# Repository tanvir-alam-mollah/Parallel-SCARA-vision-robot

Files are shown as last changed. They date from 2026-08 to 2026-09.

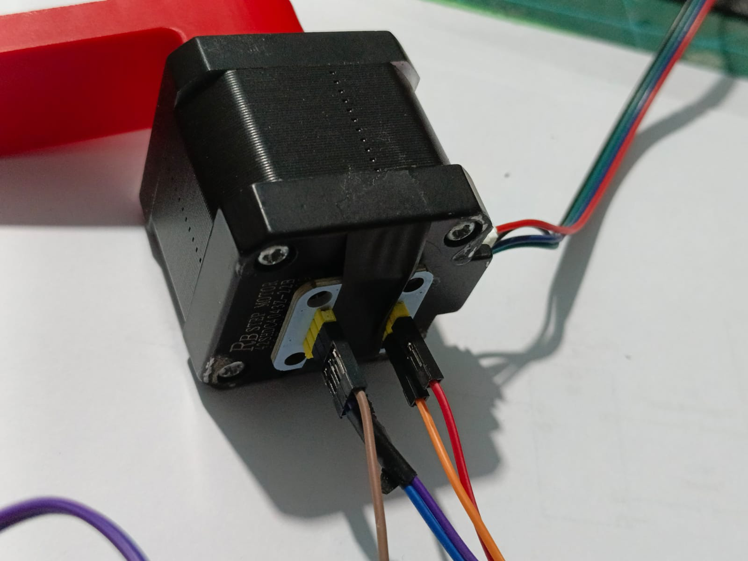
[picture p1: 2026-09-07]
image and videos/encoder Mounting2.jpeg

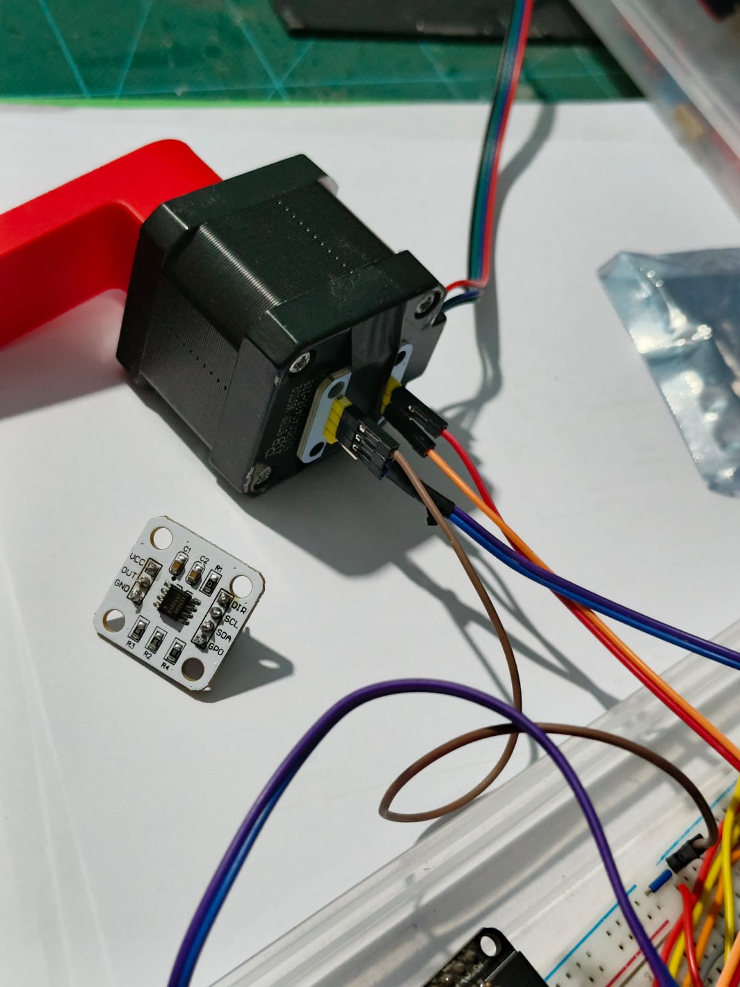
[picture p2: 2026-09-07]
image and videos/encoder Mounting.jpeg

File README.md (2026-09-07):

# Autonomous 5-Bar Parallel SCARA Manipulator
**Developer:** Md Tanvir Alam Mollah, Mechatronics Engineering, KUET  
**Domain:** Autonomous Systems Integration & Closed-Loop Robotics  





## 📌 Project Overview
A direct-drive, 2-DOF parallel robotic manipulator designed for fully autonomous pick-and-place operations. This project bridges advanced mechanical kinematics with real-time computer vision, allowing the system to identify targets within a calibrated workspace, compute real-world cartesian coordinates, and execute precision sorting using a custom electromagnet end-effector. 

To guarantee absolute physical precision, the system incorporates a closed-loop feedback architecture. By utilizing AS5600 magnetic encoders to count the physical steps of the stepper motors, the microcontroller continuously verifies the true position of the end-effector against the calculated kinematic targets.

## ✨ Key Features
*   **Dynamic Inverse Kinematics (IK):** Mathematical IK natively derived and executed on the ESP32 to calculate complex joint angles in real time.
*   **Closed-Loop Position Feedback:** Dual AS5600 magnetic encoders count the physical steps executed by the NEMA 17 motors, verifying the exact position of the end-effector and forming a precise error-correction feedback loop.
*   **Computer Vision Pipeline:** OpenCV-based object detection over an IP camera stream, transforming pixel data into real-world cartesian coordinates (0.875 mm/px scale).
*   **Visual Auto-Homing (`VHOME`):** The system dynamically calibrates its starting coordinate by visually locating a fiducial marker on the end-effector at startup, eliminating the need for hardcoded home steps.
*   **Handshake Protocol Automation:** A robust serial communication architecture between Python and the ESP32 that orchestrates the full autonomous task loop (Identify $\rightarrow$ Grasp $\rightarrow$ Transport $\rightarrow$ Release $\rightarrow$ Reset).
*   **Live UI/UX Overlay:** Projects a persistent 100mm physical coordinate grid directly onto the video feed to monitor the manipulator's reach and spatial accuracy continuously.

## 🛠️ Hardware Architecture
*   **Microcontroller:** ESP32 DevKit V1
*   **Actuators:** 2x NEMA 17 Stepper Motors (Direct Drive) driven by DRV8825 modules (1/32 Microstepping).
*   **Position Feedback:** 2x AS5600 High-Resolution Magnetic Encoders operating on independent hardware I2C buses.
*   **End-Effector:** 5V DC Electromagnet (P25/20, 5kg holding capacity, 0.6A draw) controlled via a 1-Channel 5V Relay.
*   **Logic Level Management:** 3.3V to 5V relay mismatch resolved via software-defined High-Impedance switching (`pinMode` toggling).

## 📐 Mechanical Workspace & Kinematics
*   **Base Origins:** Left Motor (X: -40.0, Y: 0.0) | Right Motor (X: 40.0, Y: 0.0)
*   **Linkages:** Base Links (110.0 mm) | End Links (160.0 mm)
*   **Trajectory:** Uses `FastAccelStepper` for interrupt-driven trapezoidal motion profiling (Acceleration: 2000 steps/s²).

## 🚀 Current Status & Next Steps
The manipulator's kinematics, vision pipeline, and open-loop control are fully operational.

**Active Development:** Implementing the closed-loop feedback system. Dual AS5600 magnetic encoders are being mapped via independent hardware I2C buses to count the exact physical steps of the NEMA 17 motors. This feedback loop will continuously verify the mechanical execution of the Inverse Kinematics, ensuring the end-effector has successfully reached the assigned coordinates and compensating for any missed stepper motor steps.

---

### 📂 Repository Structure
*   `/firmware` - ESP32 C++ source code, kinematics math, and stepper control logic.
*   `/vision` - Python scripts for OpenCV target tracking, auto-homing, and serial communication.
*   `/docs` - Wiring diagrams, mechanical parameters, and system architecture notes.
*   `/cad` - 3D models and assembly files for the 5-bar linkage system.



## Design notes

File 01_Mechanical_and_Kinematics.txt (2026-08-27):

PROJECT: 5-Bar Parallel SCARA Manipulator
=========================================
DESCRIPTION: 
A direct-drive 2-DOF parallel robotic manipulator designed for automated pick-and-place operations. The system uses a computer vision pipeline to dynamically calculate inverse kinematics and physically sort objects using an electromagnet end-effector.

MECHANICAL PARAMETERS:
- Actuators: 2x NEMA 17 Stepper Motors (Direct Drive)
- End-Effector: 5V DC Electromagnet (Model: P25/20, 5kg holding force, 0.6A current draw)
- Workspace Base Origins: 
  - Left Motor (Base 1): X = -40.0 mm, Y = 0.0 mm
  - Right Motor (Base 2): X = 40.0 mm, Y = 0.0 mm
- Linkage Dimensions:
  - Base Links (Link 1 & Link 2): 110.0 mm
  - End Links (Link 3 & Link 4): 160.0 mm

KINEMATICS:
The system uses mathematical Inverse Kinematics (IK) to convert cartesian target coordinates (X, Y) into radian joint angles for the stepper motors. The formula utilizes the law of cosines and trigonometric mapping (atan2, hypot) to constantly ensure targets fall within the physical envelope of the mechanical linkages.

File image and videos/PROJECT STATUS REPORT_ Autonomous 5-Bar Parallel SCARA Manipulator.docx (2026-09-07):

# PROJECT STATUS REPORT: Autonomous 5-Bar Parallel SCARA Manipulator

Date: September 7, 2026

## 1. Ultimate Project Objective

The overarching objective of this project is to engineer, program, and validate a fully autonomous, closed-loop 5-bar parallel SCARA robotic manipulator capable of visual targeting and physical object sorting.

The system bridges advanced mechanical kinematics with real-time computer vision to identify targets within a physical workspace, compute precise real-world cartesian coordinates, and execute pick-and-place operations using a specialized electromagnet end-effector.

To ensure research-grade physical precision, the ultimate iteration of this system integrates a strict closed-loop feedback architecture. By mapping dual AS5600 magnetic encoders to the stepper motor shafts, the microcontroller will continuously verify the mechanical execution of the Inverse Kinematics (IK), establishing a real-time error-correction loop that guarantees absolute end-effector positional accuracy.

## 2. Progress Update: Completed Milestones

The project has successfully transitioned through the foundational mechanical, electrical, and software phases. The system is currently fully operational in an open-loop state.

Previously:

1. Kinematics & Motion Control (Firmware):
  a. Successfully derived and embedded mathematical Inverse Kinematics natively onto the ESP32 to calculate complex joint angles in real time.
  b. Configured NEMA 17 stepper motors with DRV8825 drivers, utilizing the FastAccelStepper library for high-speed, interrupt-driven trapezoidal motion profiling.
2. Electrical & End-Effector Integration:
  a. Successfully integrated a 5V DC Electromagnet (P25/20) with a ~5kg holding capacity.
  b. Resolved a critical 3.3V-to-5V hardware logic-level mismatch on the control relay by implementing software-defined High-Impedance state switching (pinMode toggling).
  c. Stabilized the magnetic coil with a dedicated 2A external power supply, optimizing magnetic flux dwell times for reliable payload securing.

Last 2 weeks:

3. Computer Vision Pipeline (Software):
  a. Deployed an OpenCV-based tracking pipeline over an IP Web camera stream, accurately transforming detected pixel data (u,v) into real-world cartesian coordinates (x,y).
  b. Calibrated to a 0.875 mm/px scale.
4. Full-Cycle Autonomy:
  a. Established a robust serial "Handshake Protocol" between Python and the ESP32.
  b. Implemented a visual auto-homing sequence (VHOME) that dynamically calibrates the manipulator's starting coordinates by visually locating a green fiducial marker on the end-effector.
  c. Automated the comprehensive task loop (VPICK): Target identification, precision grasping, transport to a designated drop zone (X: 150, Y: 0), payload release, and safe retreat (X: 0, Y: 150).

UPLOAD THE VIDEO!!

## 3. Ongoing Tasks: The Closed-Loop Integration Roadmap

While the open-loop system functions smoothly, the manipulator currently relies blindly on the stepper motors executing their commanded step counts. The final phase of the project is entirely focused on hardware feedback and error correction.

### Immediate Objectives (Hardware & Wiring)

- Dual I2C Bus Configuration: Wire the two AS5600 magnetic encoders to the ESP32. Because the AS5600 has a hardcoded I2C address (0x36), the sensors will be wired to the ESP32's two independent hardware I2C buses (Bus 0: GPIO 25/27, Bus 1: GPIO 32/33) to prevent signal clashing without requiring a multiplexer.
- Baseline Sensor Validation: Write and execute standalone diagnostic firmware to ensure both encoders smoothly output 12-bit raw angle data (0–4095) across a full 360-degree rotation of the NEMA 17 shafts.

### Secondary Objectives (Software & Algorithms)

- Resolution Mapping: Develop the mathematical conversion matrix to bridge the gap between the NEMA 17's microstepping resolution (6,400 steps per revolution at 1/32 mode) and the AS5600's fixed magnetic tick resolution (4,096 ticks per revolution).
- Closed-Loop Feedback Implementation:
  - Modify the main execution loop to read the starting AS5600 angles prior to movement.
  - Command the physical step sequence derived from the IK calculations.
  - Read the post-movement AS5600 angles, convert the raw data into degrees, and compare it against the IK target angles.
  - Calculate the discrepancy (error margin) and command corrective micro-steps if the end-effector falls short of the target coordinate.

### Remaining Tasks:

1. 3d print the workspace setup and fully mount the system
2. Calibration
3. System Benchmarking: Run extensive pick-and-place cycles under varying speeds and payloads to document the correction latency and overall positional accuracy of the closed-loop system.
4. Documentation: Finalize code commenting, GitHub repository archiving, and compile the final thesis/project report.

Git repo:

https://github.com/tanvir-alam-mollah/Parallel-SCARA-vision-robot.git

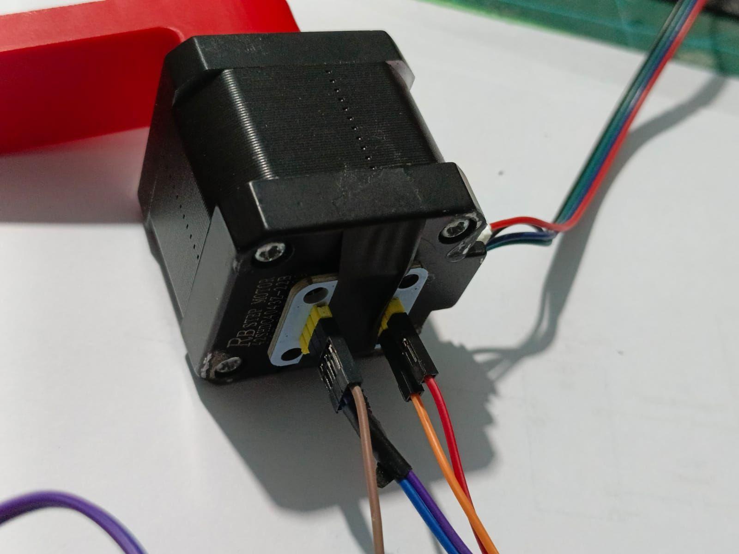
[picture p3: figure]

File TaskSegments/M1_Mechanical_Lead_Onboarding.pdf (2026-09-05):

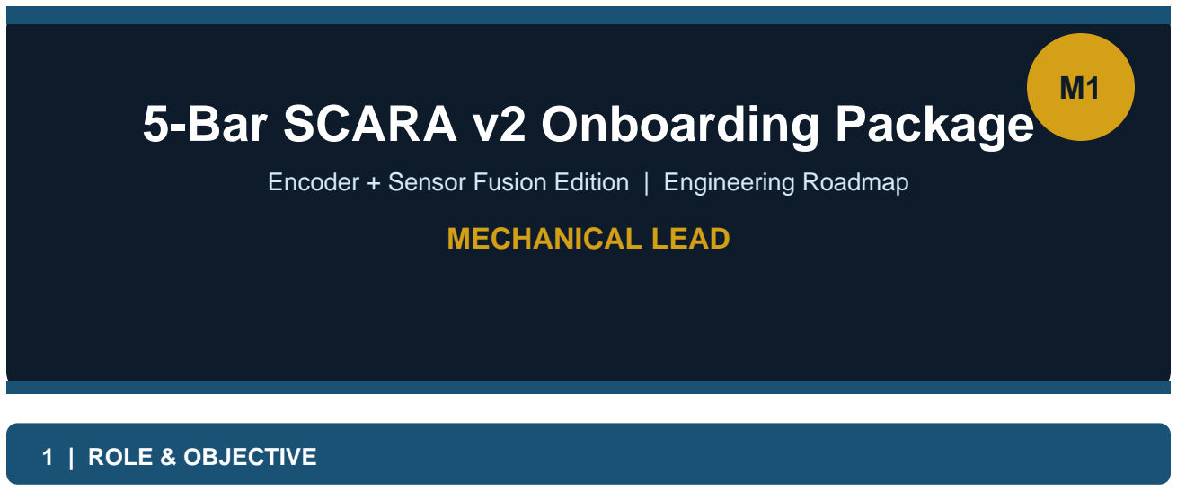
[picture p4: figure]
5-Bar SCARA v2 Onboarding Package; MECHANICAL LEAD; 1 | ROLE & OBJECTIVE

### Encoder + Sensor Fusion Edition | Engineering Roadmap

As Mechanical Lead (M1), you are the geometric and physical foundation of the entire project. Your mission is two-fold: extract precise kinematic parameters (L1–L4, d) to ±0.1 mm, and physically mount and validate the rotary encoders on both NEMA 17 motor shafts. Every downstream firmware component — IK solver, closed-loop correction, collision detection — depends on the accuracy of your measurements. You own Phase 1 outright and provide hardware support for Phase 2B.
Primary Mission: Deliver a fully-populated config.h with all geometric and encoder constants, verified by oscilloscope, and committed to Git before M2 can begin Phase 2B.

### 2 | HARDWARE & COMPONENTS REQUIRED

Component | Specification / Notes | Quantity
NEMA 17 Stepper Motors | Already installed on SCARA frame | 2
Rotary Encoder (Magnetic) | AS5600 I2C OR LPD3806-600BM-G5-24C quadrature, 600 PPR | 2
Encoder Mounting Brackets | Custom-printed or machined; must be rigid (zero flex) | 2
Digital Calipers | Resolution ±0.01 mm; calibrated | 1
Dial Indicator + Magnetic Stand | For runout check — must verify < 0.1 mm eccentricity | 1
Oscilloscope / Logic Analyzer | To verify clean A/B quadrature square waves at full speed | 1
Decoupling Capacitors | 100 nF ceramic; 1 per encoder signal line (4 total) | 4+
Shielded Signal Cable | For A/B encoder channels; route away from motor power leads | As needed
Alignment Tape / Marker | Physical home-position marking on workspace | 1
Screws, Standoffs, Epoxy | For rigid bracket + motor housing attachment | Assorted

### 3 | SOFTWARE & PLATFORMS REQUIRED

5-Bar SCARA v2 | M1 — Mechanical Lead | CONFIDENTIAL — Internal Use Only
Page 2 | 5-Bar Parallel SCARA — Onboarding Document | M1
Tool / Library | Purpose | Installation
Arduino IDE 2.x or PlatformIO | Edit and verify config.h constants | arduino.cc / platformio.org
ESP32 Board Package (Espressif) | For ESP32 pin definitions referenced in
config.h | Board Manager URL
Git (CLI or GitHub Desktop) | Version control — commit v0.0-baseline
and config.h | git-scm.com
VSCode + C/C++ Extension | Syntax highlighting for config.h editing | code.visualstudio.com
Logic Analyzer Software | Pulseview (open source) to decode
quadrature signals | sigrok.org
Spreadsheet (Excel / Sheets) | Record 5x measurement sets and
compute means | Office / Google

### 4 | AI INTEGRATION STRATEGY

Use AI to validate your measurements, automate config.h generation, and troubleshoot encoder wiring. Below are specific, copy-paste-ready prompt strategies:

### Prompt 1 — Generate config.h from your measurements:

"I measured the 5-bar SCARA linkage parameters: L1=118.4mm, L2=120.1mm, L3=117.9mm, L4=119.6mm, d=95.0mm. The encoder is LPD3806 with 600 PPR using quadrature x4 decoding. Generate a complete config.h with all constexpr values, GPIO pin assignments for ESP32 interrupt-capable pins, and inline comments explaining each constant. Format it as Arduino C++."

### Prompt 2 — Diagnose encoder signal quality:

"I see my quadrature encoder A/B signals on oscilloscope. The A channel has clean edges but B channel has a 50ns ringing glitch after each edge. My wiring runs parallel to the stepper motor coil wires for ~15cm. What are the likely causes and fixes? Explain EMI coupling and decoupling capacitor placement."

### Prompt 3 — Validate bracket design:

"I need to mount a rotary encoder to a NEMA 17 motor shaft. The encoder body must not flex. List the mechanical design requirements for the bracket, runout constraints, and how to verify concentricity with a dial indicator. Provide a step-by-step procedure."

### 5 | BASIC ARCHITECTURE & CONNECTIONS

Your Deliverable | Connects To | Why It Matters
config.h (L1–L4, d) | M2 — IK Solver (Phase 2) | IK math uses these exact values; 1mm error
= positioning fault
Encoder PPR, GPIO pins | M2 — Encoder ISR (Phase 2B) | ISR must know which GPIO and CPR to
decode counts correctly
Physical home marker | M6 — Baseline Audit
(Pre-Phase)

M6 needs reference position before Git commit

Encoder wire routing | M5 — Reviewer (Phase 2B) | M5 checks EMI isolation and signal integrity
Oscilloscope verification | M5 — TEST 1-D sign-off | Gate requirement; no clean signal = Phase 1
blocked

Page 3 | 5-Bar Parallel SCARA — Onboarding Document | M1
Your Deliverable | Connects To | Why It Matters

Rigid bracket + runout <

0.1mm | M2 — Closed-loop accuracy | Mechanical slop propagates into position
error directly

Data Flow: M6 baseline commit → M1 physical measurements + encoder mount → M2 IK firmware → M2 encoder ISR → M4 integration → M5/M6 validation

### 6 | TIMELINE & MILESTONES

[ DAY 1 ]
- Attend kickoff with M6 — confirm Git repo access and review v0.0-baseline tag
- Gather all measurement tools (calipers, dial indicator, oscilloscope)
- Print or acquire encoder mounting brackets; order encoders if not in stock
- Review config.h skeleton from M6's Pre-Phase deliverable

[ DAYS 2–3 (Phase 1 Core) ]
- Measure L1, L2, L3, L4 five times each — record in spreadsheet, compute means
- Measure d (motor pivot separation) five times — record mean
- Measure joint backlash in ±X and ±Y with dial indicator
- Mark and photograph world frame origin on workspace surface

[ DAYS 3–4 (Encoder Mounting — NEW v2) ]
- Mount encoder body to motor housing using rigid bracket (zero flex)
- Attach encoder disk to motor shaft — verify concentricity with dial indicator (runout < 0.1mm)
- Route A/B cables AWAY from motor power wires; add 100nF decoupling caps at ESP32 pins
- Connect encoder to ESP32 on interrupt-capable pins (ENC1_A=34, ENC1_B=35, ENC2_A=36, ENC2_B=39)

[ DAY 5 (Verification Gate) ]
- Oscilloscope check: clean square waves on A and B at full motor speed — no glitches
- Populate config.h: L1–L4, d, ENCODER_PPR=600, ENC_CPR=2400, GPIO pin assignments
- Commit config.h to Git — coordinate with M6 for tag/branch naming
- M5 reviews: TEST 1-A through 1-E — obtain sign-off

[ PHASE 2B HW SUPPORT ]
- Support M2 during encoder homing: zero both encoder counts at physical home position
- Verify 3 known angles physically — confirm encoder within ±2 counts of expected
- If stall detection triggers incorrectly: check for mechanical binding, tighten bracket
- Sign off on Phase 2B HW portion with M5 and M2

### 7 | ESCALATION MATRIX

Issue / Blocker | First Contact | Second Contact | Notes

Measurement ambiguity /

linkage geometry unclear | M6 (Systems Lead) | M2 (uses values in IK) | Remeasure and document
| | disagreement
| | lines
Self-resolve: redesign bracket | M6 for fabrication resources | Do NOT proceed to firmware until resolved

Encoder signal glitches persist

after decoupling caps | M2 (Firmware) | M5 (Test Lead) | Try ferrite bead on signal

Encoder bracket flexes —
runout > 0.1mm

Page 4 | 5-Bar Parallel SCARA — Onboarding Document | M1
Issue / Blocker | First Contact | Second Contact | Notes
GPIO pin conflict with M2's firmware | M2 (pin ownership) | M6 (config arbitration) | Update config.h together
Git merge conflict on config.h | M6 (Git custodian) | M4 (Integration) | M6 resolves baseline conflicts
Phase gate blocked — M5 not available for review | M5 directly | M6 for escalation | Gate CANNOT be bypassed

You are the physical foundation of this system. Every millimeter of precision you deliver multiplies through the entire kinematic chain. Measure twice, commit once. You've got this. ■

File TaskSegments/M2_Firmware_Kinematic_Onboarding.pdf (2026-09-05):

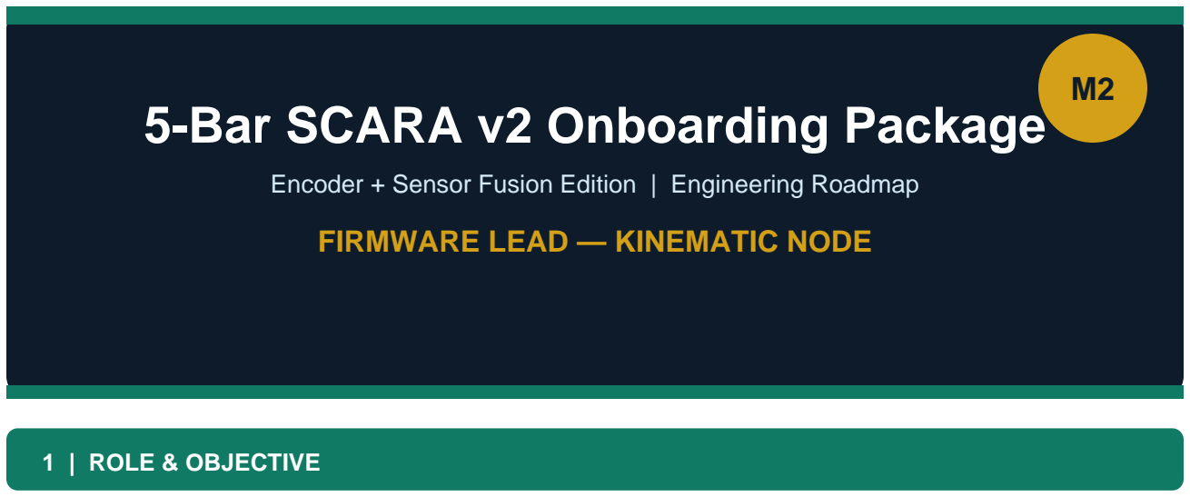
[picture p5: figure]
5-Bar SCARA v2 Onboarding Package; FIRMWARE LEAD — KINEMATIC NODE; 1 | ROLE & OBJECTIVE

### Encoder + Sensor Fusion Edition | Engineering Roadmap

As Firmware Lead — Kinematic Node (M2), you are the computational brain of the robot arm. Your mission spans two critical phases: Phase 2 — build the closed-form IK solver, 2D collision monitor, and interrupt-driven state machine (open-loop baseline); and Phase 2B — layer quadrature encoder decoding, a closed-loop position correction engine, and stall detection onto that foundation. You also serve as reviewer for M1's mechanical output.
Primary Mission: Deliver firmware on the ESP32 (dual-core) that reliably accepts FusionPackets from M4, resolves inverse kinematics, drives AccelStepper motors, and uses encoder feedback to verify and correct each commanded position — all in real time without blocking the main loop.

### 2 | HARDWARE & COMPONENTS REQUIRED

Component | Specification / Notes | Qty
ESP32 Dev Board (dual-core) | Main kinematic processing node; must have 4
interrupt-capable GPIO free | 1
DRV8825 Stepper Drivers | One per motor; set microstepping to 1/16 or 1/32 | 2
NEMA 17 Stepper Motors | As mounted by M1 on SCARA frame | 2
Rotary Encoders (mounted by M1) | LPD3806 600PPR or AS5600; A/B signals on GPIO
34,35,36,39 | 2
Power Supply (12V, >3A) | For DRV8825 VMot; separate from ESP32 3.3V rail | 1
Logic Level Converter | If encoder signals are 5V — convert to 3.3V for ESP32 | As
needed
Oscilloscope / Serial Monitor | Verify ISR counts, step pulses, correction loop
behavior | 1
USB-to-Serial Adapter | For flashing and Serial monitor on ESP32 | 1

### 3 | SOFTWARE & PLATFORMS REQUIRED

Tool / Library | Purpose | Source
Arduino IDE 2.x or PlatformIO | Primary firmware development
environment | arduino.cc / platformio.org

5-Bar SCARA v2 | M2 — Firmware Lead (Kinematic) | CONFIDENTIAL — Internal Use Only
Page 2 | 5-Bar Parallel SCARA — Onboarding Document | M2
Tool / Library | Purpose | Source
Espressif ESP32 Board Package | FreeRTOS, IRAM_ATTR, hardware timers, noInterrupts() | Board Manager
AccelStepper Library | Non-blocking stepper motor control (.run() in main loop) | Library Manager
ESP-NOW (built-in) | Receive FusionPacket from M4's vision bridge | Included in ESP32 core
FreeRTOS (built-in) | Run stall detection check_stall() as a timed task | Included in ESP32 core
Git | Version control; review M1's config.h before Phase 2 | git-scm.com
Python + matplotlib (optional) | Plot encoder count vs. step count during calibration | pip install matplotlib

### 4 | AI INTEGRATION STRATEGY

Your work is mathematically dense (IK geometry, ISR timing, FreeRTOS task scheduling). Use AI as a pair-programmer for derivation verification, ISR debugging, and test generation:

### Prompt 1 — Verify your IK math (law of cosines):

"I have a 5-bar parallel SCARA with Motor 1 at P1=(-d/2, 0) and Motor 2 at P2=(+d/2, 0). Link lengths are L1=118.4, L2=120.1, L3=117.9, L4=119.6, d=95.0 (all mm). Derive the closed-form elbow-out IK solution for both chains using law of cosines. Show the atan2+alpha formulation for theta1 and theta2. Clamp cos values to [-1,1]. Return as Arduino C++ function IKResult solve_ik(float x, float y)."

### Prompt 2 — Debug quadrature ISR jitter:

"My ESP32 quadrature decoder ISR uses the QEM[16] lookup table. At high motor speeds I see occasional count errors of +2 or -2 per revolution. The encoder is 600PPR. Diagnose possible causes: bounce, cache miss latency, simultaneous A+B edge timing. How does IRAM_ATTR help? What is the maximum safe RPM before ISR misses edges?"

### Prompt 3 — Generate TEST 2-A validation code:

"Generate an Arduino test sketch that validates my IK solver with 20 random (x,y) workspace points. For each point: call solve_ik(), then forward-kinematics to recover (x,y), then compute Euclidean error. Print PASS if all errors < 0.5mm, FAIL otherwise. Include the forward kinematics for a 5-bar parallel robot given theta1, theta2, L1-L4, d."

### Prompt 4 — State machine review:

"Review this RobotState enum and main loop pattern for a pick-and-place robot: [paste your state machine code]. Identify any blocking call that would starve AccelStepper.run(), any state transition that could skip a state under fast packet arrival, and any missing FAULT recovery path."

### 5 | BASIC ARCHITECTURE & CONNECTIONS

Input From | Your Processing | Output To

M1: config.h (L1–L4, d, GPIO,
PPR)
| IK solver reads all geometric constants at
compile time
| | M4: acknowledgment + motor
state

Page 3 | 5-Bar Parallel SCARA — Onboarding Document | M2
Input From | Your Processing | Output To
M4: FusionPacket (X,Y,Vx,Vy,confidence) | Parse packet → IK → collision check → moveTo() | DRV8825 → NEMA 17 motors
Encoders (A/B pulses via ISR) | Quadrature decode → angle comparison → correction move | M5: stall alerts via Serial
M1: home position marker | Zero encoder counts at startup homing routine | M5 reviewer: Phase 2B gate
M3: velocity hints (Vx,Vy) | Pre-position if confidence > 180 threshold | Reduced pick latency

Core Loop: ESP-NOW ISR (IRAM_ATTR) receives FusionPacket → main loop reads g_target → solve_ik() → check_collision() → moveTo() → motor1.run()/motor2.run() → apply_correction() → check_stall() [50ms hardware timer]

### 6 | TIMELINE & MILESTONES

[ DAY 1 ]
- Pull config.h from M1 (or Git baseline) — read all geometric constants
- Set up PlatformIO project with ESP32 target and AccelStepper dependency
- Stub out IKResult struct and solve_ik() function signature
- Coordinate with M4 on FusionPacket struct definition (v2 version)

[ DAYS 2–5 (Phase 2 — IK Solver & State Machine) ]
- Implement IK solver: law of cosines, atan2 + alpha, elbow-out branch for both chains
- Implement 2D collision monitor using cross-product segment intersection
- Build state machine: IDLE → HOMING → MOVING_TO_PICK → PICKING → MOVING_TO_DROP → DROPPING → FAULT
- TEST 2-A: IK round-trip error < ±0.5mm on 20 random workspace points
- TEST 2-B: Collision detector 100% accuracy on 20 known test cases
- TEST 2-C: State machine driven by Serial mock packets — full IDLE→PICK→DROP→IDLE cycle
- TEST 2-D: Out-of-workspace target silently rejected
- M1 reviews Phase 2 — obtain sign-off

[ DAYS 6–8 (Phase 2B — Encoder Closed-Loop) ]
- Implement isr_enc1() and isr_enc2() with IRAM_ATTR and QEM[16] lookup table
- Implement attach_encoders() with CHANGE interrupts on all 4 encoder pins
- Thread-safe get_enc1_angle_deg() and get_enc2_angle_deg() with noInterrupts()
- Implement apply_correction(): proportional correction loop, max 3 attempts
- Implement check_stall(): 50ms FreeRTOS timer, STALL_COUNT_THRESHOLD=20 counts
- TEST 2B-A: Encoder direction — +90° command → count = +ENC_CPR/4
- TEST 2B-B: Correction triggered when linkage manually held
- TEST 2B-C: FAULT triggered within 700ms of shaft block
- TEST 2B-D: 10 pick positions, encoder error < ±1.5 deg each
- TEST 2B-E: Zero drift in 30 seconds idle
- M5 reviews Phase 2B — obtain sign-off

### 7 | ESCALATION MATRIX

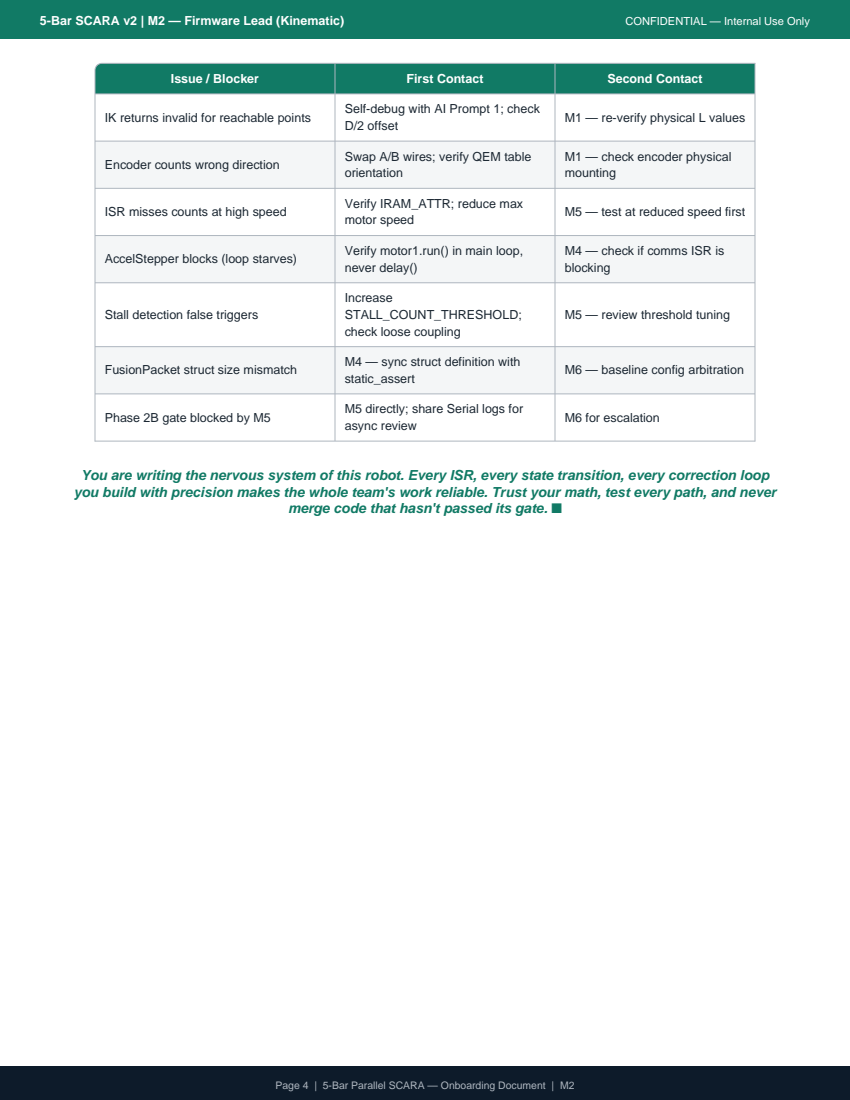
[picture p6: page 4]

Issue / Blocker | First Contact | Second Contact

IK returns invalid for reachable points | Self-debug with AI Prompt 1; check D/2 offset | M1 — re-verify physical L values

Encoder counts wrong direction | Swap A/B wires; verify QEM table orientation | M1 — check encoder physical mounting

ISR misses counts at high speed | Verify IRAM_ATTR; reduce max motor speed | M5 — test at reduced speed first

AccelStepper blocks (loop starves) | Verify motor1.run() in main loop, never delay() | M4 — check if comms ISR is blocking

Stall detection false triggers | Increase STALL_COUNT_THRESHOLD; check loose coupling | M5 — review threshold tuning

FusionPacket struct size mismatch | M4 — sync struct definition with static_assert | M6 — baseline config arbitration

Phase 2B gate blocked by M5 | M5 directly; share Serial logs for async review | M6 for escalation

You are writing the nervous system of this robot. Every ISR, every state transition, every correction loop
you build with precision makes the whole team's work reliable. Trust your math, test every path, and never

merge code that hasn't passed its gate. ■

Page 4 | 5-Bar Parallel SCARA — Onboarding Document | M2

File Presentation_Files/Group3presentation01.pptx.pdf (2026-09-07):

MTE 4108

# Vision Guided Parallel SCARA for Precise pick & place operation

### Automated Sorting System

## Group - 3 2131014 2131019

Presenter: Md Tanvir Alam Mollah [ Roll : 2131017 ]

00.

# Hardware Implementation

## Core Components

Sensors
- Overhead Vision Camera
- Rotary Encoders and Magnetic Encoder

Actuation
Base-grounded NEMA 17 stepper motors with DRV8825 drivers 1/32 microstepping).

Mechanics
Custom 10 mm thick planar linkages for high Z-axis rigidity.

Control & Vision
ESP32 and ESP32CAM.

End-Effector
5V Electromagnet with active-low relay isolation.

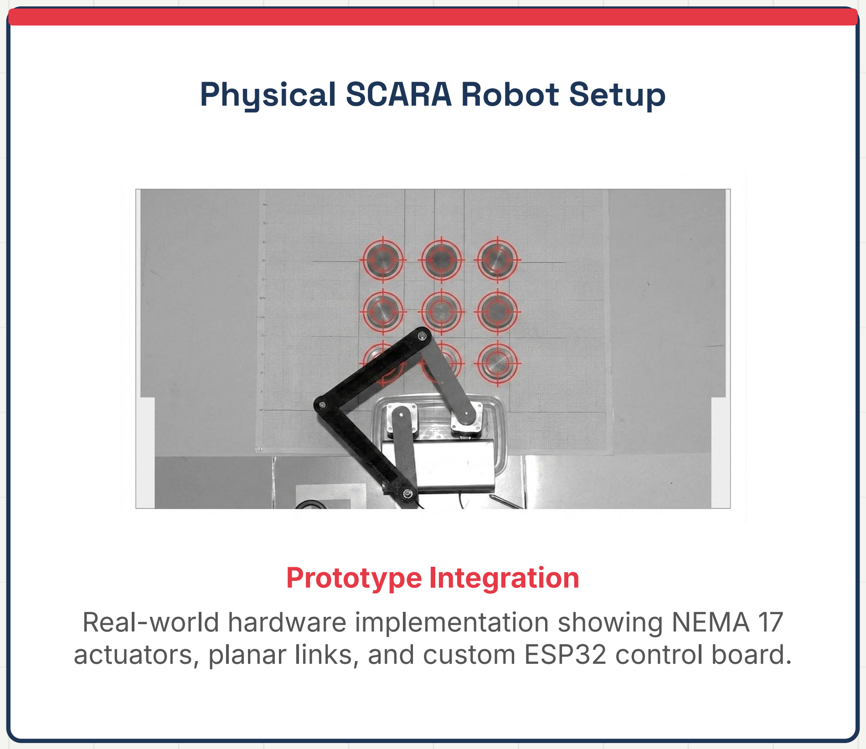
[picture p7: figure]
Physical SCARA Robot Setup; Prototype Integration

Real-world hardware implementation showing NEMA 17 actuators, planar links, and custom ESP32 control board.

System Architecture

# Overall Execution Pipeline

## The system operates through a highly efficient, five-step decentralized pipeline:

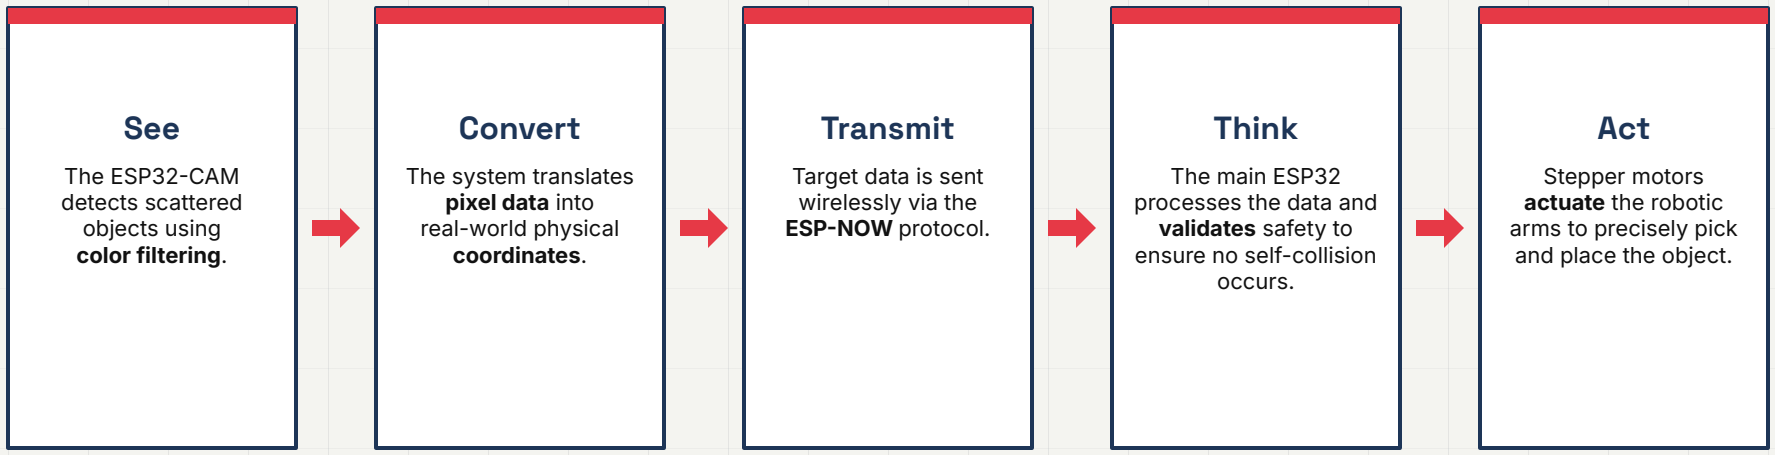
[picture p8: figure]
See; The ESP32CAM detects scattered objects using color filtering.; Convert; The system translates pixel data into real-world physical coordinates.; Transmit; Target data is sent wirelessly via the ESPNOW protocol.; Think; The main ESP32 processes the data and validates safety to ensure no self-collision occurs.; Act; Stepper motors actuate the robotic arms to precisely pick and place the object.

01 .

# See (Object Detection)

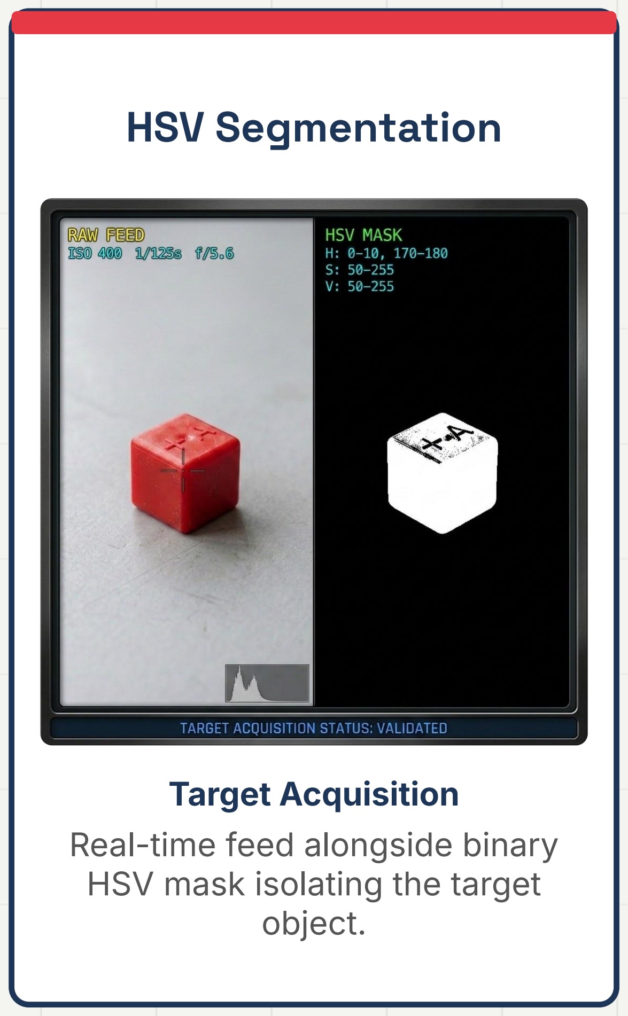
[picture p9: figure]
HSV Segmentation; Target Acquisition Real-time feed alongside binary HSV mask isolating the target object.
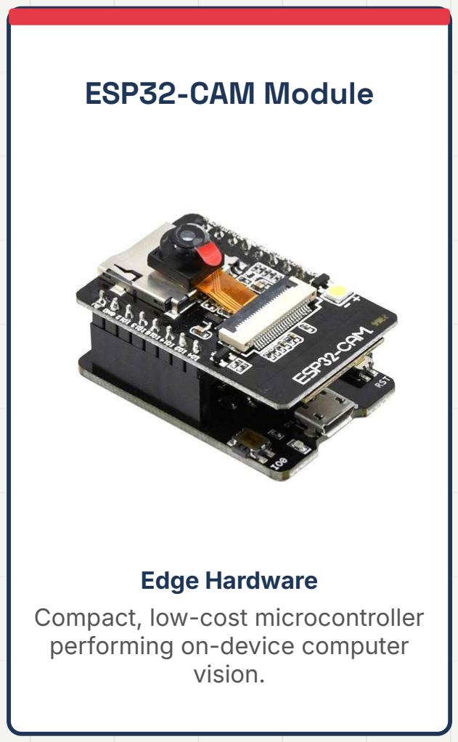
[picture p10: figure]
ESP32-CAM Module; Edge Hardware Compact, low-cost microcontroller performing on-device computer vision.

## Workspace Capture & Segmentation

Overhead Capture: An overhead ESP32CAM continuously monitors and captures the workspace environment in real-time.

Color Filtering: Lightweight, efficient color filtering algorithms detect scattered target objects dynamically.

HSV Isolation: Raw RGB data is converted to the HSV color space to completely isolate the target object from background noise entirely on the edge device.

02 .

# Convert – Spatial Mapping

Homography & Translation

# Pixel-to-Physical Calibration

Centroid Detection
The vision node isolates the geometric center (centroid) of the detected object as a precise pixel value U, V.

Mathematical Translation
The system mathematically translates this localized pixel data into real-world physical coordinates.

Planar Homography
A planar homography transformation matrix scales and translates optical data into physical Cartesian coordinates X, Y) in millimeters.

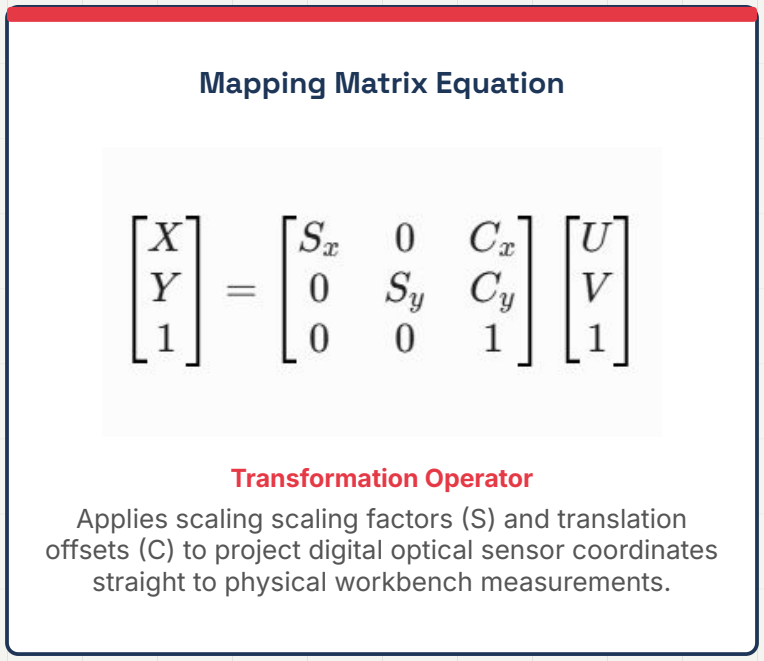
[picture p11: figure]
Mapping Matrix Equation; Transformation Operator; straight to physical workbench measurements.

Applies scaling scaling factors S) and translation offsets C) to project digital optical sensor coordinates

03 .

# Transmit – Wireless Telemetry

# Direct Node-to-Node Link

Vision-to-Kinematics Link
The calculated target data is sent wirelessly from the vision node to the kinematic node in real-time.

ESP-NOW Protocol
Data transmission relies on the connectionless “ESPNOW protocolˮ for efficient, direct MAC-to-MAC communication.

Deterministic Pipeline
Bypassing traditional Wi-Fi routers guarantees a highly stable, deterministic, microsecond-latency data pipeline.

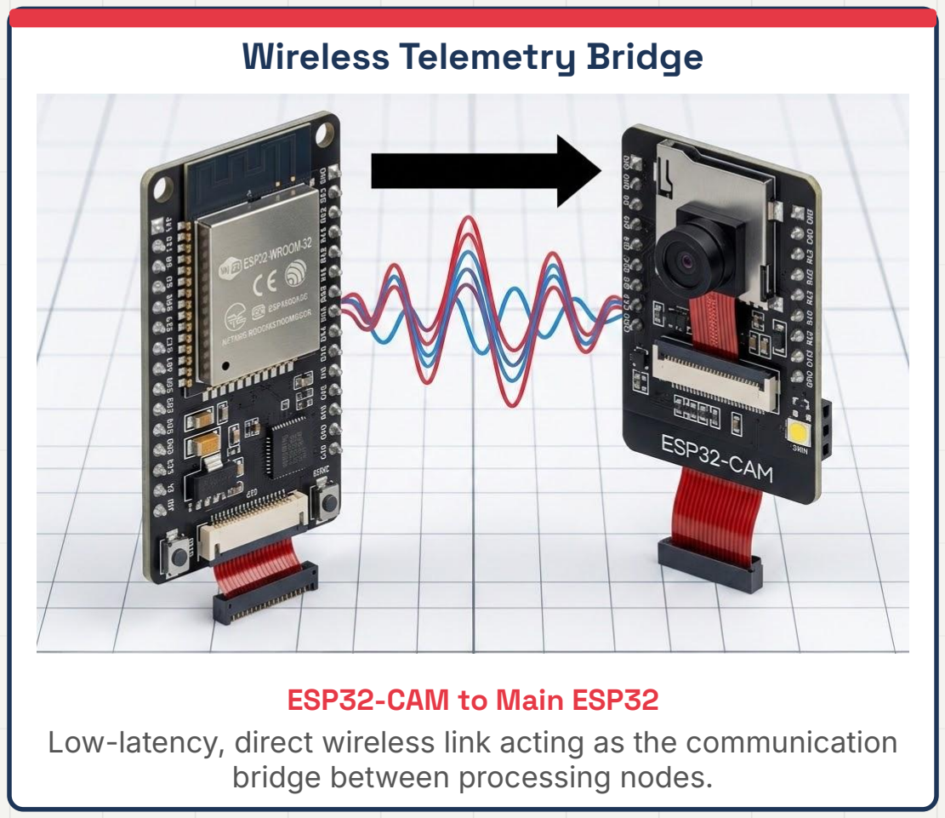
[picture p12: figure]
Wireless Telemetry Bridge; ESP32-CAM to Main ESP32; bridge between processing nodes.

Low-latency, direct wireless link acting as the communication

04 .

# Think – Kinematics & Safety

## Kinematics & Safety Pipeline

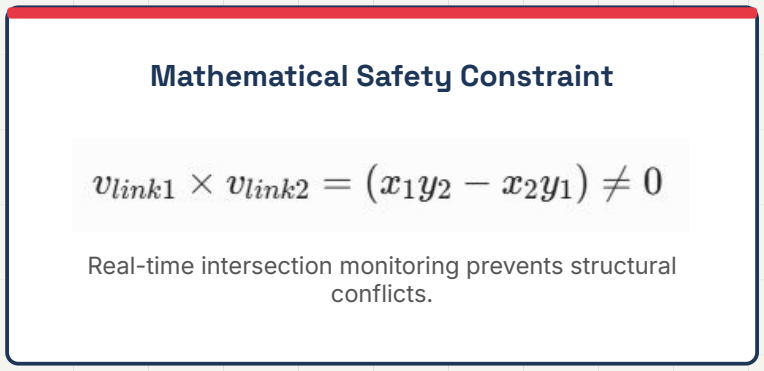
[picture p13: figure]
Mathematical Safety Constraint; Real-time intersection monitoring prevents structural conflicts.

### 1. Target Processing

The main ESP32 processes the received X, Y) target data through the inverse kinematics solver in real-time.

### 2. Trajectory Validation

The controller mathematically validates the proposed trajectory to guarantee that no self-collision occurs during execution.

### 3. Linkage Verification

A 2D cross-product line-intersection monitor verifies the safety of the 10 mm linkages before authorizing motor movement.

04 .

# Kinematic Modelling (IK Solver)

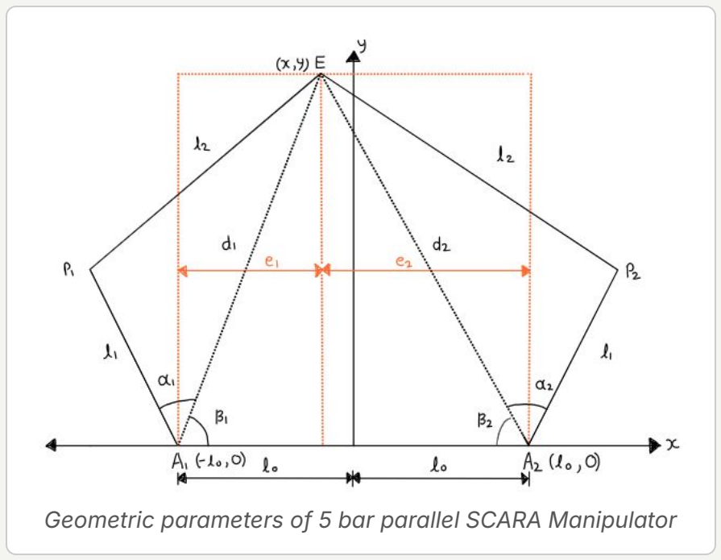
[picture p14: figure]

Geometric parameters of 5 bar parallel SCARA Manipulator

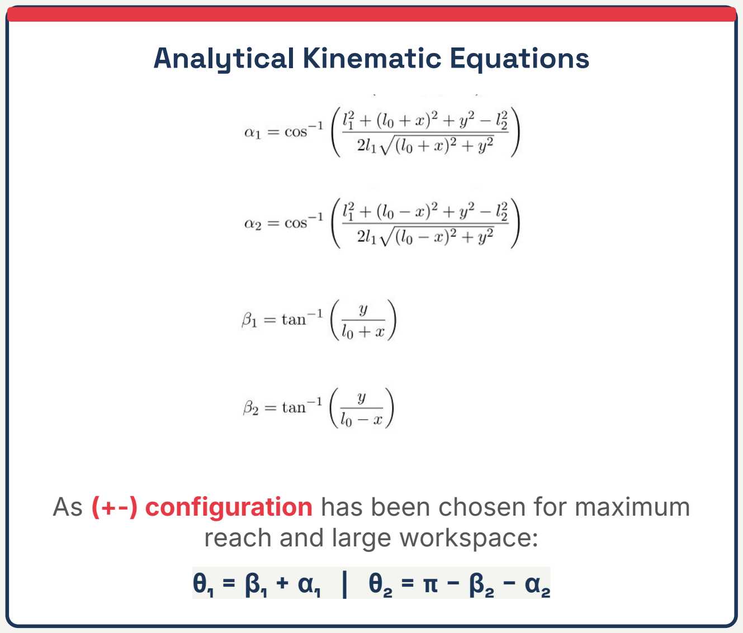
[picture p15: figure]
Analytical Kinematic Equations; reach and large workspace:

As (+-) configuration has been chosen for maximum

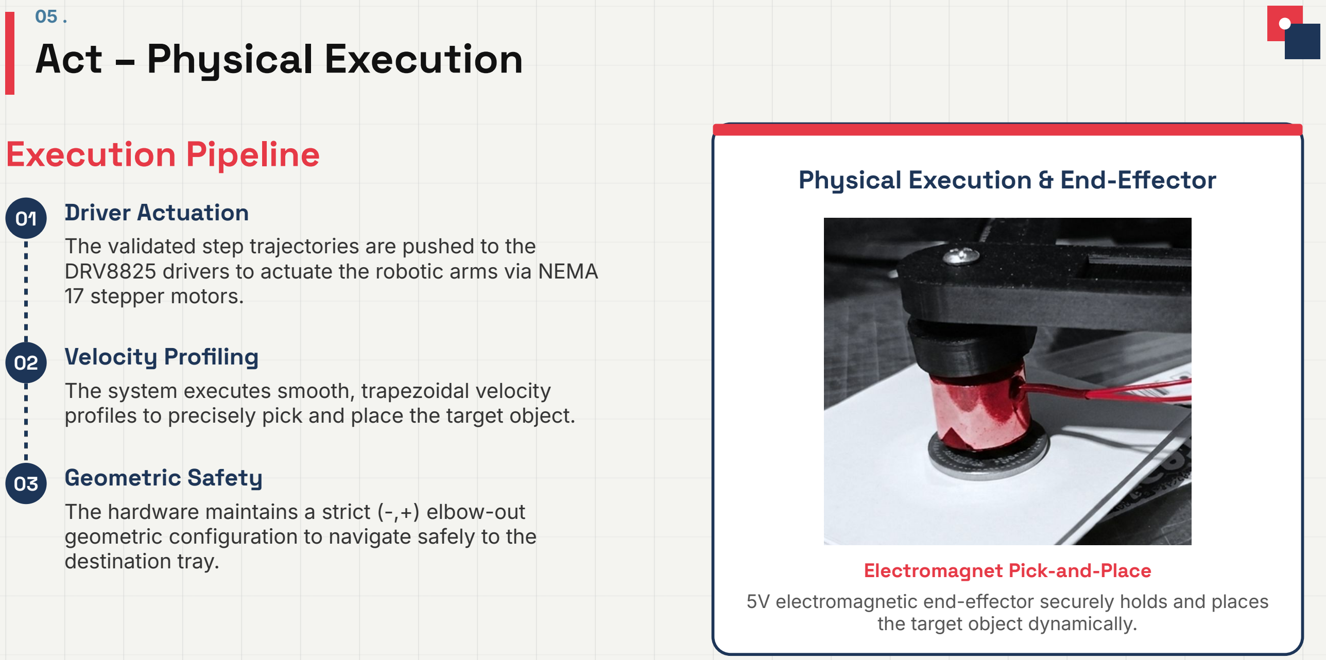
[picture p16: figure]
05 . Act – Physical Execution; Execution Pipeline; 01 Driver Actuation; 17 stepper motors.; 02 Velocity Profiling; 03 Geometric Safety; destination tray.; Physical Execution & End-Effector; Electromagnet Pick-and-Place; the target object dynamically.

The validated step trajectories are pushed to the DRV8825 drivers to actuate the robotic arms via NEMA

The system executes smooth, trapezoidal velocity profiles to precisely pick and place the target object.

The hardware maintains a strict (-,+) elbow-out geometric configuration to navigate safely to the

5V electromagnetic end-effector securely holds and places

# Thank you

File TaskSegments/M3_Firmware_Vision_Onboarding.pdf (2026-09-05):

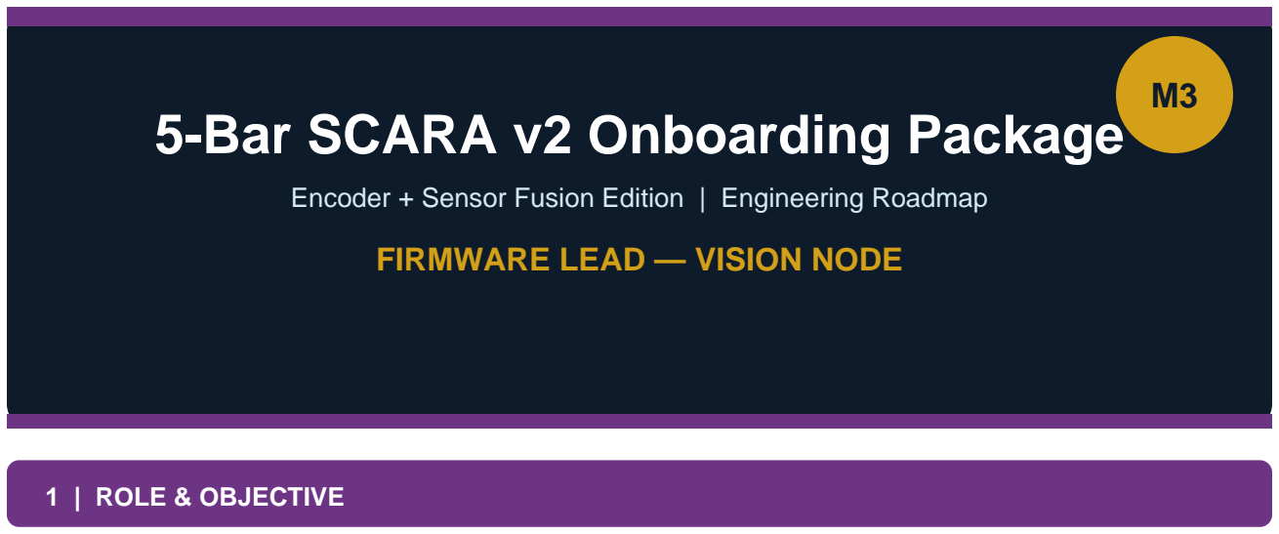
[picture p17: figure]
5-Bar SCARA v2 Onboarding Package; FIRMWARE LEAD — VISION NODE; 1 | ROLE & OBJECTIVE

### Encoder + Sensor Fusion Edition | Engineering Roadmap

As Firmware Lead — Vision Node (M3), you are the eyes of the SCARA system. Your mission covers two phases: Phase 3 — build a deterministic QVGA HSV color-detection pipeline running on the ESP32-CAM (OV2640) with sub-80ms latency and centroid accuracy under 3mm; and Phase 3B — fuse that raw centroid measurement with a frame-differencing optical flow estimate inside a 2D Kalman filter, producing a smoothed, predictive (X, Y, Vx, Vy) state that survives brief occlusions.
Primary Mission: Deliver a FusionPacket containing fused position and velocity to M4's ESP-NOW bridge with confidence scoring, enabling M2 to pre-position the arm before the target is stationary.

### 2 | HARDWARE & COMPONENTS REQUIRED

Component | Specification / Notes | Qty
ESP32-CAM Module (AI-Thinker) | OV2640 sensor; PSRAM mandatory for QVGA RGB565 buffers | 1
OV2640 Camera (attached) | QVGA (320×240) PIXFORMAT_RGB565; lock exposure/gain/WB after calibration | 1
LED Ring Light | Uniform illumination across workspace; eliminates ambient variation | 1
9-Point Calibration Grid | 3×3 dot pattern at known world coordinates; print on flat surface | 1
USB-to-Serial (FTDI) | For flashing ESP32-CAM (no onboard USB); 3.3V logic | 1
Tripod / Camera Mount | Rigid overhead mount; no vibration; < 0.1mm positional drift | 1
30nF / 100nF Capacitors | Power supply decoupling at ESP32-CAM VCC pin | 2+
Test Objects (colored) | Distinct HSV colors for calibration; flat, matte surface preferred | 3+

### 3 | SOFTWARE & PLATFORMS REQUIRED

5-Bar SCARA v2 | M3 — Firmware Lead (Vision) | CONFIDENTIAL — Internal Use Only
Page 2 | 5-Bar Parallel SCARA — Onboarding Document | M3
Tool / Library | Purpose | Source
Arduino IDE / PlatformIO | Primary firmware development for ESP32-CAM | arduino.cc
esp32-camera library (Espressif) | Camera init, PSRAM allocation, frame grab | GitHub: espressif/esp32-camera
ESP-NOW (built-in) | Transmit FusionPacket to M4's kinematic bridge | ESP32 core
PSRAM APIs (ps_malloc) | Mandatory for 153,600-byte RGB565 frame + 76,800-byte mask | Built-in to ESP32 core
Python + numpy + matplotlib | Plot raw centroid vs. Kalman output during tuning; compute RMS error | pip install
Serial Plotter (Arduino IDE) | Real-time visualization of Kalman state during calibration | Built-in
Git | Version control; M4 depends on FusionPacket struct header | git-scm.com

### 4 | AI INTEGRATION STRATEGY

Your work involves signal processing math (Kalman matrices, optical flow, HSV thresholding) and tight PSRAM memory management on a resource-constrained MCU. Use AI for numerical validation, parameter tuning, and pipeline bottleneck diagnosis:

### Prompt 1 — Tune Kalman filter parameters:

"I have a 2D Kalman filter tracking an object on a conveyor (constant-velocity model). State = [x, y, vx, vy]. Measurement = [x, y] from HSV centroid (noise ~3mm stddev). Current params: Q_POS=0.5, Q_VEL=2.0, R_MEAS=4.0. The filter lags 3 frames behind fast-moving objects. Explain how changing each parameter affects lag vs. noise. Suggest new values and explain the tradeoff. Show the predict-update equations."

### Prompt 2 — HSV thresholding for your target color:

"I need to detect a red object under an LED ring on an ESP32-CAM OV2640. The camera outputs RGB565. Describe the optimal HSV range for red (wraps around 0/180 in OpenCV). Provide integer-math-only C++ code to convert a single RGB565 pixel to HSV without using floats in the inner loop. How do I handle the red hue wraparound?"

### Prompt 3 — Memory budget analysis:

"ESP32-CAM with 4MB PSRAM. I need: QVGA RGB565 frame=153,600 bytes, binary mask=76,800 bytes, two 32x32 ROI buffers=2048 bytes each, KalmanState struct, camera DMA buffers. List all allocations, check if they fit in PSRAM, and flag any that must NOT use ps_malloc. What happens if fb_location is CAMERA_FB_IN_DRAM instead of PSRAM?"

### Prompt 4 — Occlusion recovery logic review:

"Review this occlusion handling code: [paste your vision_loop_iteration()]. Identify: (1) what happens if occlusion_frames exceeds MAX_OCCLUSION_FRAMES, (2) whether confidence score correctly gates transmission, (3) any memory leak if esp_camera_fb_return() is missed in an early return path."

### 5 | BASIC ARCHITECTURE & CONNECTIONS

Page 3 | 5-Bar Parallel SCARA — Onboarding Document | M3
Input From | Your Processing | Output To
OV2640 camera (PSRAM frame) | RGB565→HSV filter → binary mask → centroid (u,v) | Kalman filter update step
Previous frame ROI buffer | 32×32 block match → optical flow (dx,dy) estimate | Fuse into Kalman vx,vy
Kalman state (predict step) | Constant-velocity propagate before each frame | Predicted X,Y during occlusion
Calibration grid (9 points) | pixel_to_world scale_x, scale_y, offset_x, offset_y | M4: correct FusionPacket units
M5 reviewer (TEST 3B-A to E) | Tune Q_POS, Q_VEL, R_MEAS until all tests pass | Phase 3B gate sign-off
Your FusionPacket output | ESP-NOW transmit to M4 | M2: pre-positioning + pick

Vision Loop: esp_camera_fb_get() [PSRAM] → HSV mask → blob gate → centroid (u,v) → pixel_to_world(wx,wy) → optical flow ROI → kalman_predict() → kalman_update() → confidence score → transmit_fused()

### 6 | TIMELINE & MILESTONES

[ DAY 1 ]
- Set up ESP32-CAM flashing rig (FTDI adapter, IO0→GND for bootloader mode)
- Verify PSRAM is detected: log esp_get_free_heap_size() and esp_psram_get_size()
- Run camera demo: capture QVGA frame, print pixel count to Serial
- Sync with M4 on FusionPacket struct — agree on byte layout before Phase 3

[ DAYS 2–5 (Phase 3 — HSV Pipeline) ]
- Implement RGB565→HSV conversion in integer math (no floats in inner loop)
- Write HSV threshold filter: populate binary mask in PSRAM g_mask_buf
- Implement blob gate: reject blobs < 200px or > 30,000px
- Compute integer centroid: accumulator sum / pixel_count → (u,v)
- Implement pixel_to_world() transform with scale + offset
- Lock camera exposure, gain, white balance after initial calibration
- TEST 3-A: Pipeline latency < 80ms (millis() timing)
- TEST 3-B: 50 frames, centroid stddev < 2mm, mean error < 3mm
- TEST 3-C: Zero false positives in 100 frames with no object
- TEST 3-D: 9-point calibration grid RMS error < 3mm
- M4 reviews Phase 3 — obtain sign-off

[ DAYS 6–9 (Phase 3B — Kalman + Optical Flow) ]
- Allocate g_roi_prev and g_roi_curr in PSRAM (32×32 = 2048 bytes each)
- Implement estimate_flow(): extract V channel in ROI, SSD block match, return (dx,dy)
- Implement KalmanState struct: x,y,vx,vy,P[4][4],initialized,occlusion_frames
- Implement kalman_predict(): propagate state + covariance with Q_POS, Q_VEL
- Implement kalman_update(): innovation, Kalman gain, Joseph form covariance update
- Implement occlusion handling: dead-reckoning up to 3 frames, confidence decay
- Implement check_kalman_health(): reset on P[0][0] or P[1][1] > 100.0 mm^2
- Tune Q_POS=0.5, Q_VEL=2.0, R_MEAS=4.0 — adjust by plotting Serial output

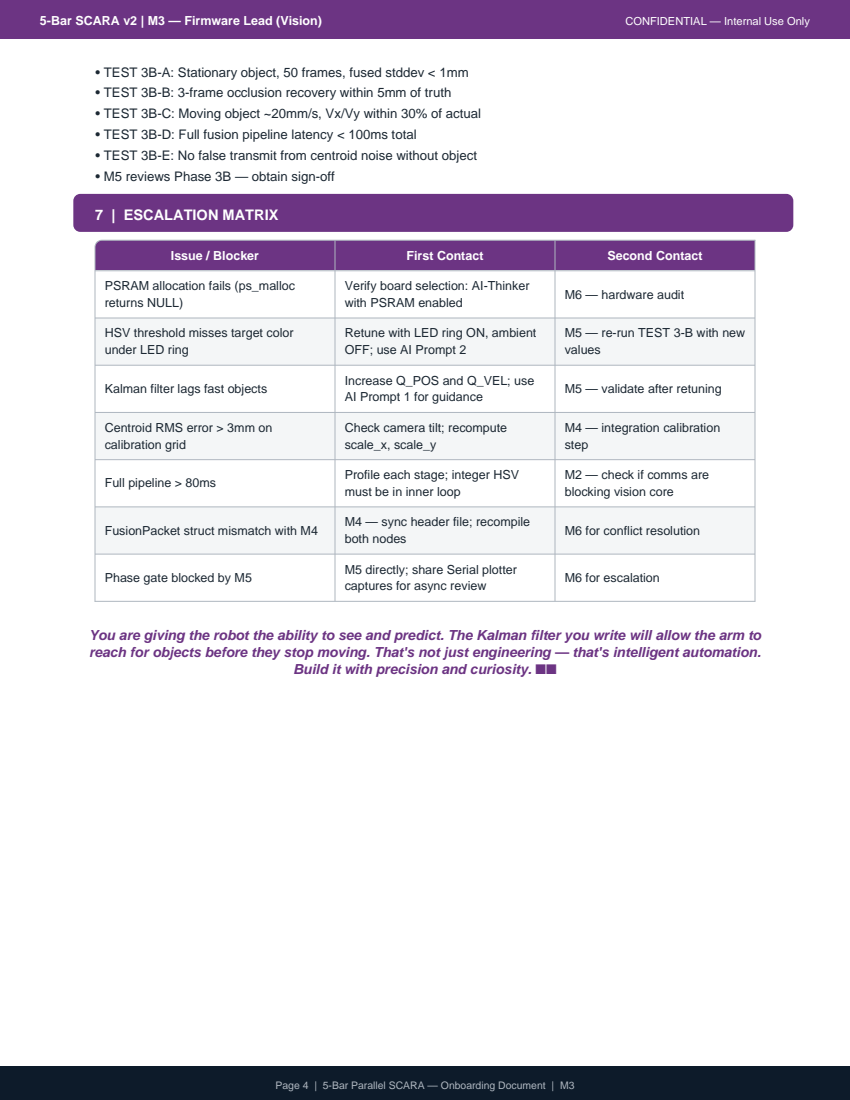
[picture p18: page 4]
7 | ESCALATION MATRIX

• TEST 3B-A: Stationary object, 50 frames, fused stddev < 1mm
• TEST 3B-B: 3-frame occlusion recovery within 5mm of truth
• TEST 3B-C: Moving object ~20mm/s, Vx/Vy within 30% of actual
• TEST 3B-D: Full fusion pipeline latency < 100ms total
• TEST 3B-E: No false transmit from centroid noise without object
• M5 reviews Phase 3B — obtain sign-off

Issue / Blocker | First Contact | Second Contact

PSRAM allocation fails (ps_malloc returns NULL) | Verify board selection: AI-Thinker with PSRAM enabled | M6 — hardware audit

HSV threshold misses target color under LED ring | Retune with LED ring ON, ambient OFF; use AI Prompt 2 | M5 — re-run TEST 3-B with new values

Kalman filter lags fast objects | Increase Q_POS and Q_VEL; use AI Prompt 1 for guidance | M5 — validate after retuning

Centroid RMS error > 3mm on calibration grid | Check camera tilt; recompute scale_x, scale_y | M4 — integration calibration step

Full pipeline > 80ms | Profile each stage; integer HSV must be in inner loop | M2 — check if comms are blocking vision core

FusionPacket struct mismatch with M4 | M4 — sync header file; recompile both nodes | M6 for conflict resolution

Phase gate blocked by M5 | M5 directly; share Serial plotter captures for async review | M6 for escalation

You are giving the robot the ability to see and predict. The Kalman filter you write will allow the arm to
reach for objects before they stop moving. That's not just engineering — that's intelligent automation.

Build it with precision and curiosity. ■■

Page 4 | 5-Bar Parallel SCARA — Onboarding Document | M3

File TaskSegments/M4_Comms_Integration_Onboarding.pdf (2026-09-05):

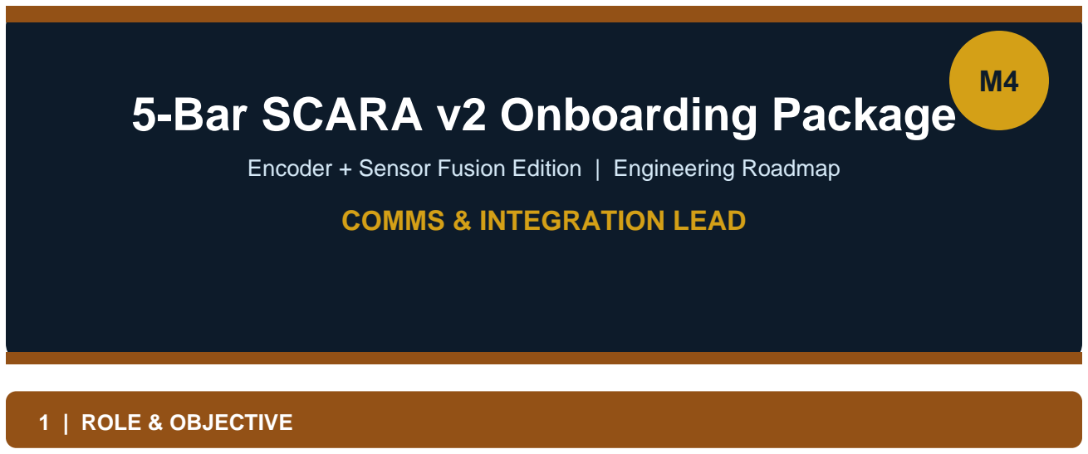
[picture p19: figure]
5-Bar SCARA v2 Onboarding Package; COMMS & INTEGRATION LEAD; 1 | ROLE & OBJECTIVE

### Encoder + Sensor Fusion Edition | Engineering Roadmap

As Comms & Integration Lead (M4), you are the connective tissue of the system. You own two complementary phases: Phase 4 — design, implement, and validate the extended ESP-NOW FusionPacket protocol that carries Kalman filter output (position + velocity + confidence) from the vision node to the kinematic node; and Phase 5 — unite all six team members' subsystems into a single, calibrated, operational closed-loop pick-and-place cycle.
Primary Mission: Deliver a <20-byte FusionPacket with CRC-16 integrity, <2% packet loss, and end-to-end latency under 15ms; then orchestrate the 9-point pixel-to-world calibration and verify the full system runs the pick-and-place cycle with encoder correction and Kalman fusion active simultaneously.

### 2 | HARDWARE & COMPONENTS REQUIRED

Component | Specification / Notes | Qty
ESP32-CAM (Vision Node) | M3's firmware flashed; acts as ESP-NOW transmitter | 1

ESP32 Dev Board (Kinematic
Node) | M2's firmware flashed; acts as ESP-NOW receiver | 1
WiFi Spectrum Analyzer (optional) | Check for 2.4GHz channel congestion near workspace | 1
Calibration Dot Grid (3×3) | Printed at known world coordinates; for 9-point
calibration | 1
USB-to-Serial Adapter | For flashing and Serial monitoring of both nodes
simultaneously | 2
Multimeter / Oscilloscope | Power rail verification during integration; relay timing
check | 1
Laptop with dual Serial monitors | Monitor both ESP32 nodes simultaneously during
integration | 1

### 3 | SOFTWARE & PLATFORMS REQUIRED

Tool / Library | Purpose | Source
Arduino IDE 2.x / PlatformIO | Develop and flash Phase 4 comms firmware | arduino.cc

5-Bar SCARA v2 | M4 — Comms & Integration Lead | CONFIDENTIAL — Internal Use Only
Page 2 | 5-Bar Parallel SCARA — Onboarding Document | M4
Tool / Library | Purpose | Source
ESP-NOW (built-in Espressif) | Peer-to-peer 2.4GHz wireless; <1ms latency; no router needed | ESP32 core
CRC-16 implementation (Arduino) | Validate packet integrity; reject corrupted bytes | Library or manual
Python + pyserial + pandas | Log 1000 packets for loss rate measurement (TEST 4-C) | pip install
Serial Monitor (both nodes) | Watch g_target fields update in real time; monitor confidence gating | Arduino IDE
Git | Coordinate FusionPacket header changes with M2 and M3 | git-scm.com
Spreadsheet | 9-point calibration: record measured vs. true coordinates, compute RMS | Excel / Sheets

### 4 | AI INTEGRATION STRATEGY

Your work requires protocol design precision, CRC implementation, and system-level integration debugging. Use AI to validate packet structure, generate test harnesses, and diagnose integration failures:

### Prompt 1 — CRC-16 implementation review:

"I need a CRC-16 (polynomial 0x8005 or CCITT 0x1021) implementation in Arduino C++ for a 20-byte FusionPacket struct. The CRC covers bytes 0–17 (first 18 bytes). Provide the crc16() function, show how to compute it at transmit side, verify at receive side, and explain why __packed__ struct is required. Also show the static_assert to verify sizeof(FusionPacket)==20 at compile time."

### Prompt 2 — Debug packet loss during integration:

"My ESP-NOW link shows ~5% packet loss in testing (1000 packet test, 50 dropped). Both nodes are 1.5 meters apart. I'm in a lab with other WiFi devices on 2.4GHz. What are the top 5 causes of ESP-NOW packet loss and how do I diagnose each? Should I change ESP-NOW channel? How does the sequence number dedup affect perceived loss rate?"

### Prompt 3 — 9-point calibration RMS calculation:

"I have 9 calibration points with known world coordinates (Xw,Yw) and measured ESP-NOW packet values (Xm,Ym). The errors are: [list your actual measurements]. Calculate RMS error. If RMS > 3mm, determine whether the error pattern suggests camera tilt (rotation error), scale drift (uniform scaling), or nonlinear distortion. Provide the corrective formula for each case."

### Prompt 4 — Integration sequence plan:

"I am integrating a 5-bar SCARA robot with these subsystems: ESP32-CAM running Kalman filter, ESP32 kinematic node with AccelStepper and encoder ISR, ESP-NOW FusionPacket link, and an electromagnet relay. List the exact integration sequence (which firmware to flash first, which Serial logs to verify at each step) to minimize debugging time. What are the top 3 failure modes at each integration step?"

### 5 | BASIC ARCHITECTURE & CONNECTIONS

Connects From | Your Role | Delivers To
M3: Kalman output (X,Y,Vx,Vy,confidence) | Pack into FusionPacket with CRC-16 and
sequence byte | M2: ESP-NOW receiver ISR

Page 3 | 5-Bar Parallel SCARA — Onboarding Document | M4
Connects From | Your Role | Delivers To
M2: confidence threshold gate | Document threshold values (>180 move, <80 idle) in firmware | Phase 5 integration test
M3: pixel-to-world calibration | Run 9-point grid; verify RMS < 3mm; update scale params | M3: update firmware constants
M2: encoder correction output | Verify correction fires post-move; log encoder error pre/post | M5: TEST 5-C sign-off
M5: electromagnet timing | Log relay energize/de-energize encoder positions | M5: interference check
All members: Phase 5 integration | Flash, connect, calibrate, and run single pick cycle end-to-end | M6: final validation handoff

Packet Flow: M3 transmit_fused() → [ESP-NOW 2.4GHz] → on_fusion_recv() ISR (M4 implements on kinematic node) → CRC check → dedup check → g_target struct → M2 state machine

### 6 | TIMELINE & MILESTONES

[ DAY 1 ]
- Sync FusionPacket struct definition with M2 and M3 — agree on all fields and byte order
- Verify ESP-NOW peer pairing works: both nodes exchange a test packet (ping/pong)
- Implement CRC-16 function; verify with a known test vector
- Review M3's Phase 3 output (SortPacket→FusionPacket migration path)

[ DAYS 2–3 (Phase 4 — FusionPacket Protocol) ]
- Implement full FusionPacket struct with #pragma pack and static_assert
- Implement on_fusion_recv() ISR with CRC guard and sequence dedup
- Implement confidence gating: >180 start move, <80 stay IDLE
- TEST 4-A: static_assert(sizeof(FusionPacket)==20) passes on BOTH projects
- TEST 4-B: End-to-end latency < 5ms average, < 15ms worst case (1000 packet log)
- TEST 4-C: Packet loss < 2% over 1000 packets
- TEST 4-D: Inject corrupted byte — verify CRC rejection, packet never accepted
- TEST 4-E: Confidence field correctly gates IDLE/MOVING transitions
- M3 reviews Phase 4 — obtain sign-off

[ DAYS 4–6 (Phase 5 — Full System Integration) ]
- Flash M3's Phase 3B firmware to ESP32-CAM; confirm Kalman output on Serial
- Flash M2's Phase 2B firmware to ESP32; confirm encoder counts at home
- Verify ESP-NOW link active; confirm g_target.confidence field populated on kinematic node
- Run single manual pick by Serial-injecting coordinates; verify encoder correction triggers
- Connect live ESP-NOW feed; verify confidence gating suppresses spurious picks
- Verify Vx,Vy non-zero in FusionPacket when object placed with a push
- Run 9-point calibration with M2 and M3; compute RMS; update scale parameters if needed
- TEST 5-A: Static pick accuracy — 4/5 trials electromagnet contacts object
- TEST 5-B: 20-cycle repeatability — ≥18/20 success at same position
- TEST 5-C: Encoder correction measurably improves accuracy (log both states)
- TEST 5-D: Fused position smoother than raw centroid over 50 frames (log both)
- TEST 5-E: Out-of-workspace target rejected, IDLE preserved

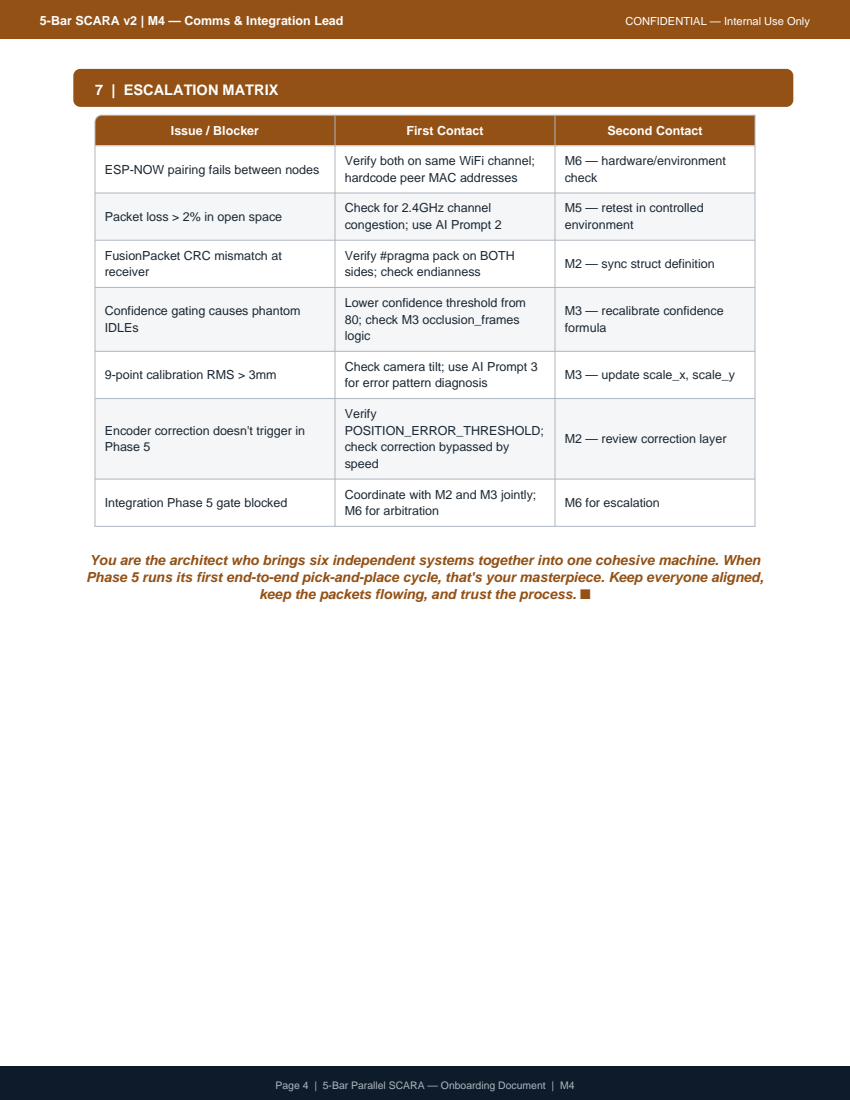
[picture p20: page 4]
7 | ESCALATION MATRIX

Issue / Blocker | First Contact | Second Contact

ESP-NOW pairing fails between nodes | Verify both on same WiFi channel; hardcode peer MAC addresses | M6 — hardware/environment check

Packet loss > 2% in open space | Check for 2.4GHz channel congestion; use AI Prompt 2 | M5 — retest in controlled environment

FusionPacket CRC mismatch at receiver | Verify #pragma pack on BOTH sides; check endianness | M2 — sync struct definition

Confidence gating causes phantom IDLEs | Lower confidence threshold from 80; check M3 occlusion_frames logic | M3 — recalibrate confidence formula

9-point calibration RMS > 3mm | Check camera tilt; use AI Prompt 3 for error pattern diagnosis | M3 — update scale_x, scale_y

Encoder correction doesn't trigger in Phase 5 | Verify POSITION_ERROR_THRESHOLD; check correction bypassed by speed | M2 — review correction layer

Integration Phase 5 gate blocked | Coordinate with M2 and M3 jointly; M6 for arbitration | M6 for escalation

You are the architect who brings six independent systems together into one cohesive machine. When
Phase 5 runs its first end-to-end pick-and-place cycle, that's your masterpiece. Keep everyone aligned,

keep the packets flowing, and trust the process. ■

Page 4 | 5-Bar Parallel SCARA — Onboarding Document | M4

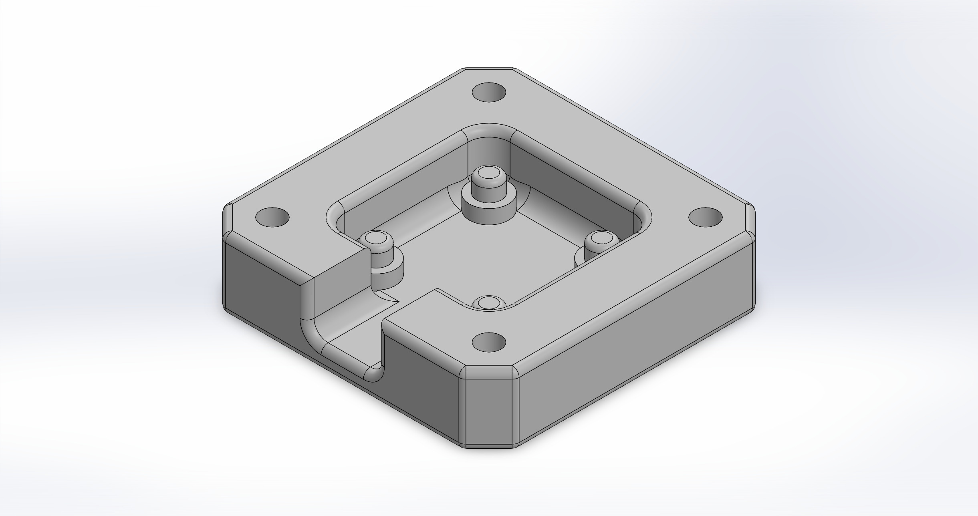
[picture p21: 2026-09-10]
MODEL/enclosure-for-as5600-magnetic-encoder-with-nema-17-stepper-motor-1.snapshot.1/encoderEncclosure.JPG

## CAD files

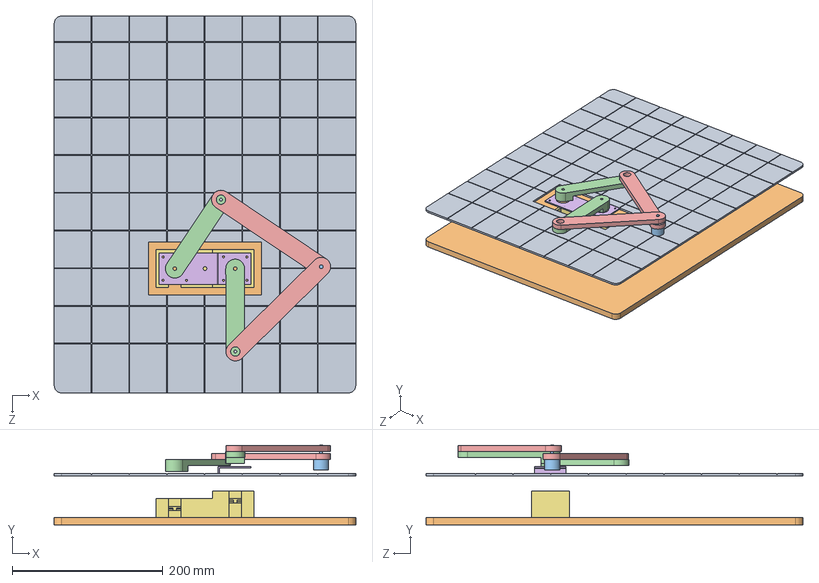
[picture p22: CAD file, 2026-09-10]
MODEL/Assem1.SLDASM
400.0 x 105.9 x 500.0 mm
motordown
motorUpMount
DistalArm x 2
ProximalArm x 2
4mm
Base
BaseUPPER

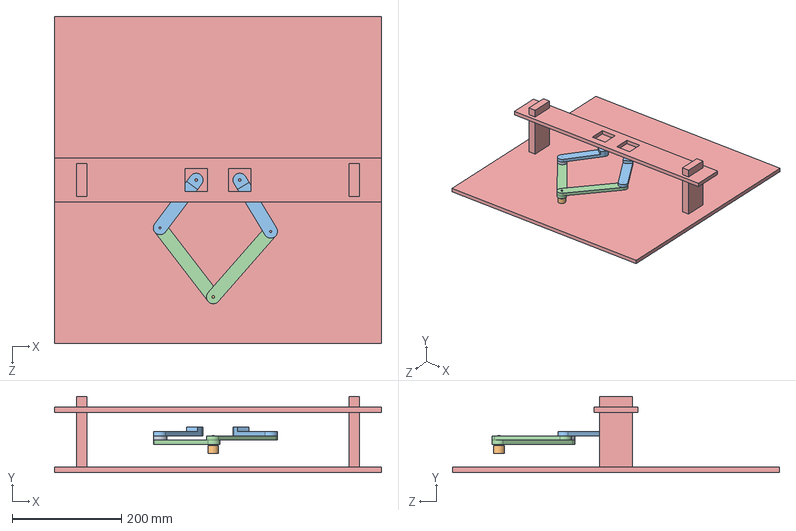
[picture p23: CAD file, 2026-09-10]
MODEL/goal.SLDASM
600.0 x 140.0 x 600.0 mm
ZONE
DistalArm x 2
ProximalArm x 2
4mm
extra

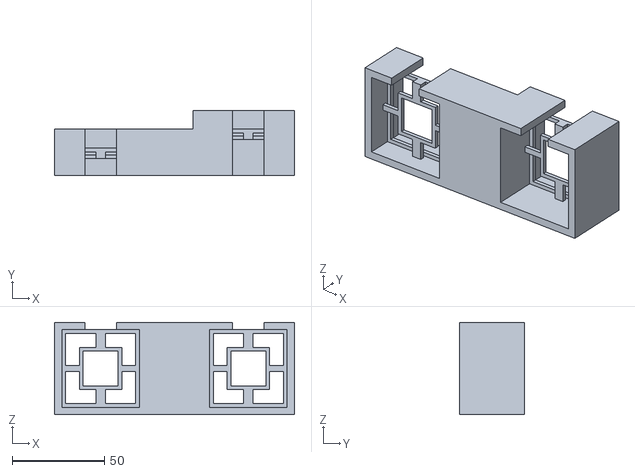
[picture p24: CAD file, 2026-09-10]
MODEL/3dPRINT/SCARAWORKSPACE/MotorMount.STL
130.0 x 35.0 x 50.0

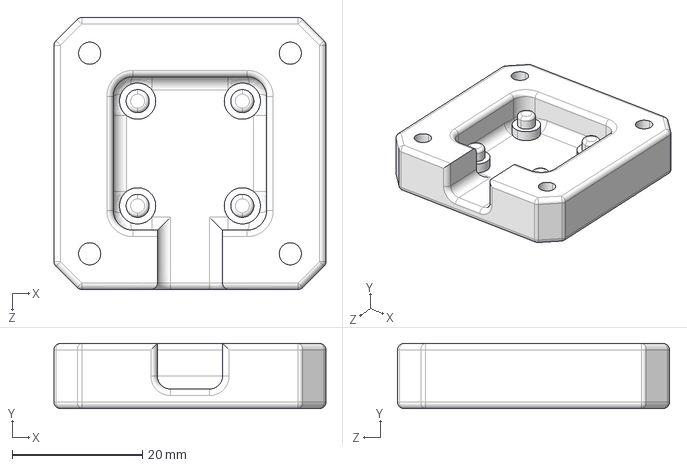
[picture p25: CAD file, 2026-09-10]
MODEL/enclosure-for-as5600-magnetic-encoder-with-nema-17-stepper-motor-1.snapshot.1/encoderEncclosure.STEP
41.7 x 10.0 x 41.7 mm

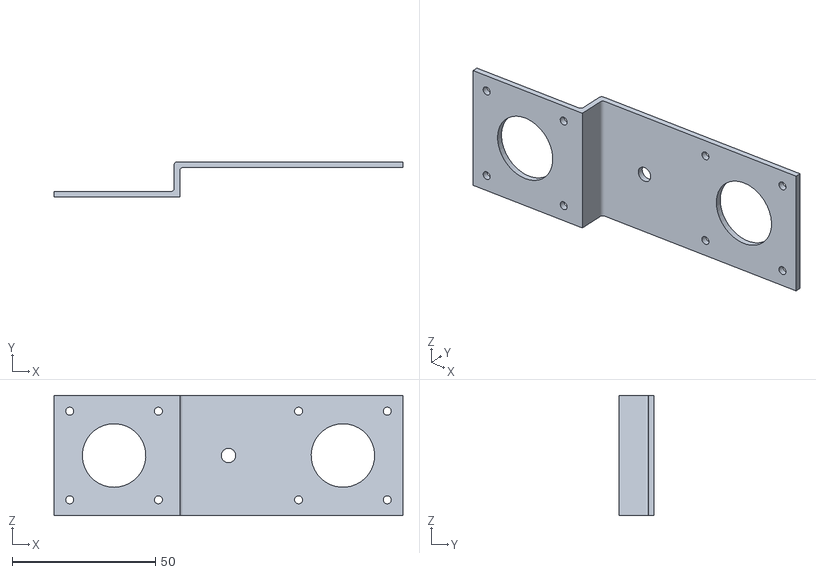
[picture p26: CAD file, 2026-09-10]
MODEL/3dPRINT/SCARAWORKSPACE/motorUpMount.STL
122.0 x 12.3 x 42.0

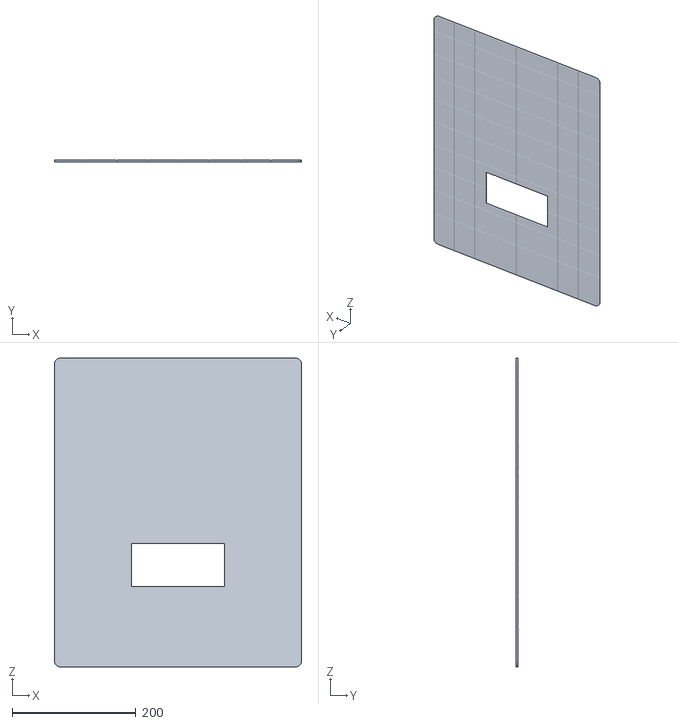
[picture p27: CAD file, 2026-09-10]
MODEL/3dPRINT/SCARAWORKSPACE/Workspace.STL
400.0 x 3.00 x 500.0

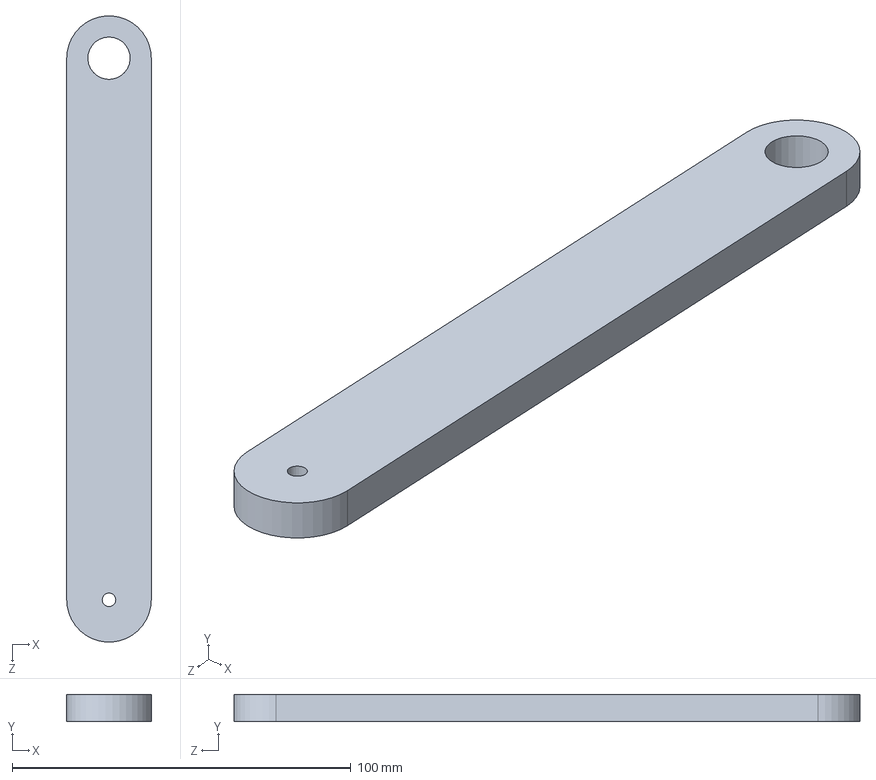
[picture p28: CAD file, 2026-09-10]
MODEL/DistalArm.SLDPRT
25.0 x 8.00 x 184.9 mm

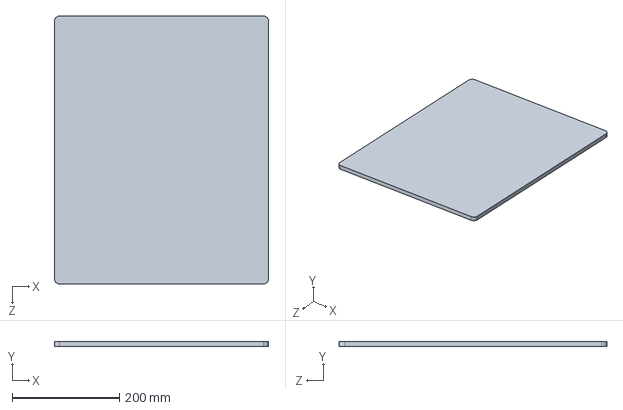
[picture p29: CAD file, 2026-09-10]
MODEL/Base.SLDPRT
400.0 x 10.0 x 500.0 mm

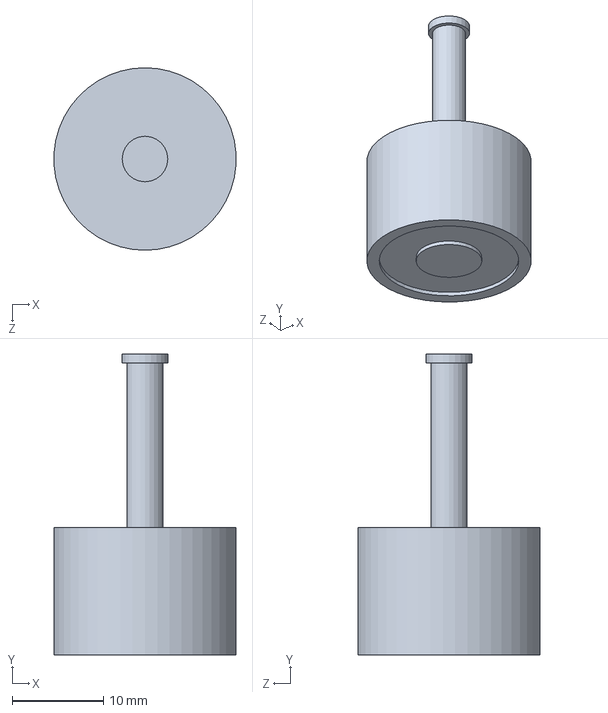
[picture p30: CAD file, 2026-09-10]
MODEL/4mm.SLDPRT
20.0 x 33.0 x 20.0 mm

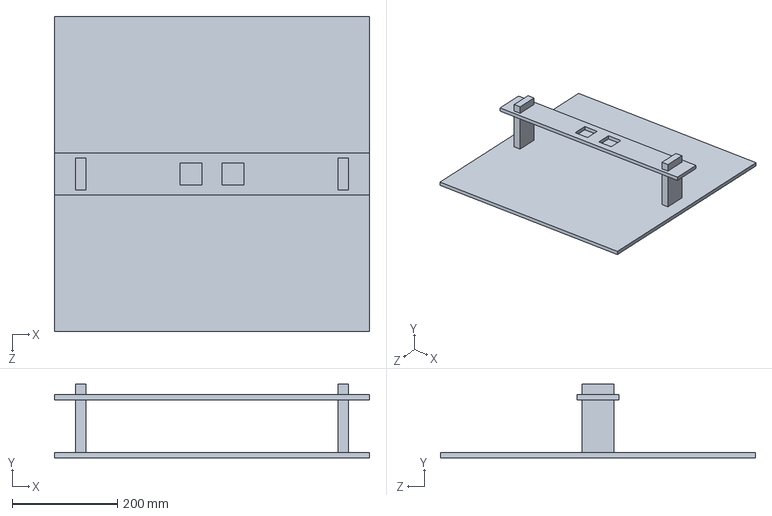
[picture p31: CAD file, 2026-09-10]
MODEL/ZONE.SLDPRT
600.0 x 140.0 x 600.0 mm

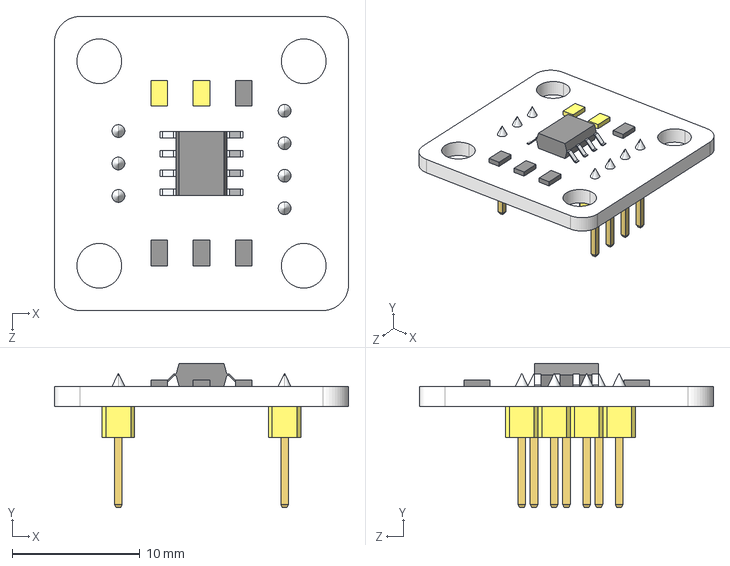
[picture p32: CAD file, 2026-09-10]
MODEL/MagneticEncoder_AS5600.STEP
23.0 x 11.3 x 23.0 mm

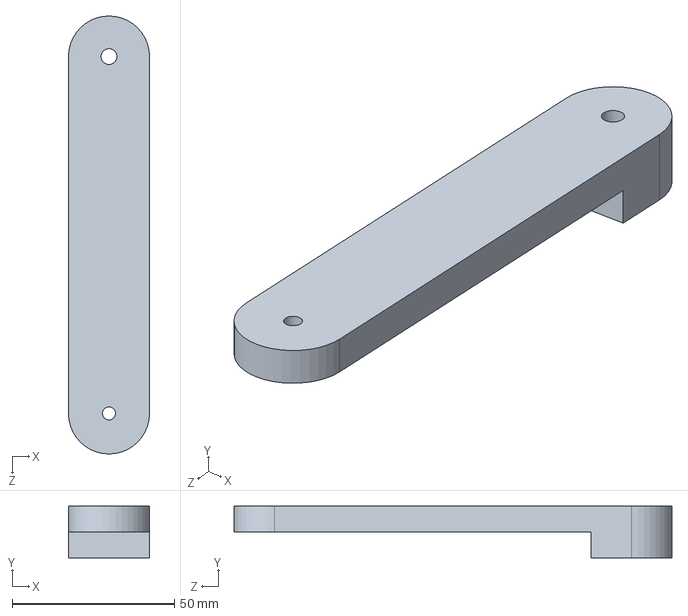
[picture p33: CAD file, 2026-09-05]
MODEL/ProximalArm.SLDPRT
25.0 x 16.0 x 135.0 mm

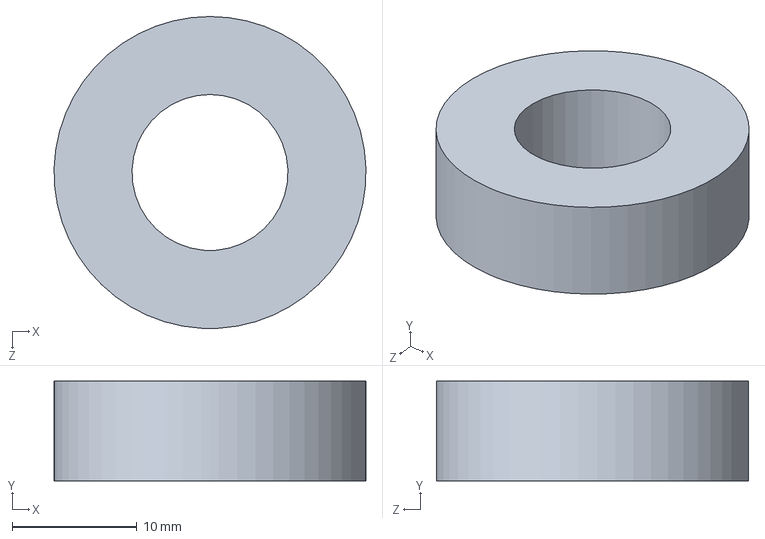
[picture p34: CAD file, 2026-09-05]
MODEL/extra.SLDPRT
25.0 x 8.00 x 25.0 mm

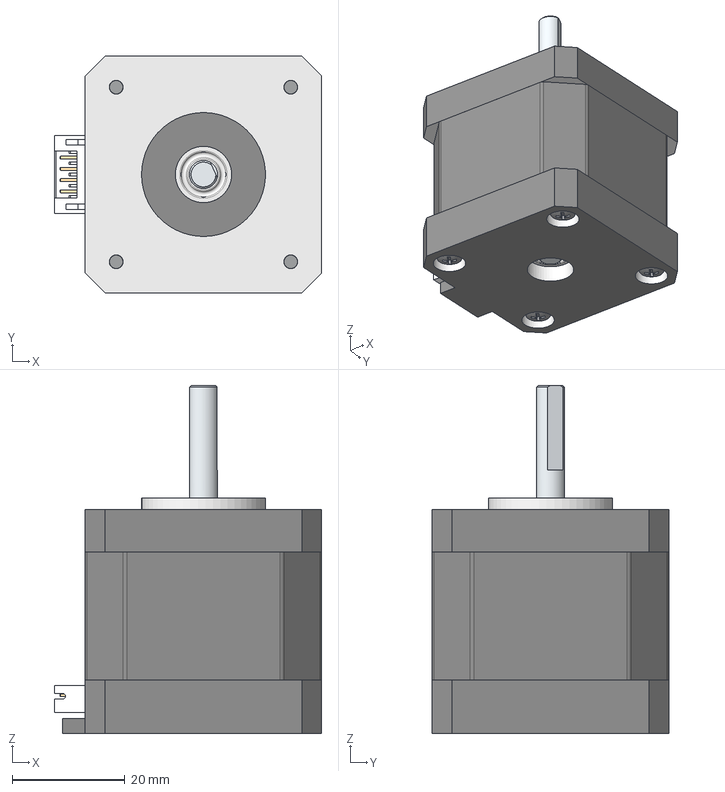
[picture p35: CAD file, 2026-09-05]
MODEL/NEMA 17 - MS17HD2.stp
47.5 x 42.0 x 61.8 mm
Middle part
Bottom plate
Top plate
Philips M3X30 x 4
JST-S6B-PH-K-S
Bearing x 2
Stepper shaft

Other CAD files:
MODEL/motorUpMount.SLDPRT
MODEL/encoderEncclosure.SLDPRT
MODEL/motordown.SLDPRT
MODEL/BaseUPPER.SLDPRT
MODEL/MagneticEncoder_AS5600.SLDPRT
MODEL/Nima 17 40x42x5mm.SLDPRT
MODEL/cam_holder.SLDPRT
MODEL/enclosure-for-as5600-magnetic-encoder-with-nema-17-stepper-motor-1.snapshot.1/encoderEncclosure.SLDPRT
cad/4mm.SLDPRT
cad/Base.SLDPRT
cad/DistalArm.SLDPRT
cad/Nima 17 40x42x5mm.SLDPRT
cad/ZONE.SLDPRT
cad/cam_holder.SLDPRT
cad/goal.SLDASM

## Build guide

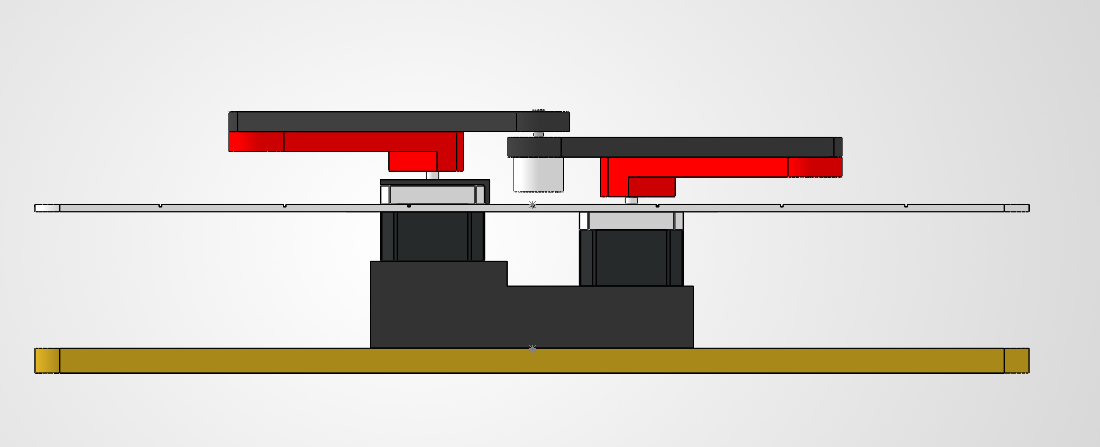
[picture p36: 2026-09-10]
MODEL/3dPRINT/MODEL PIC/Capture1.PNG

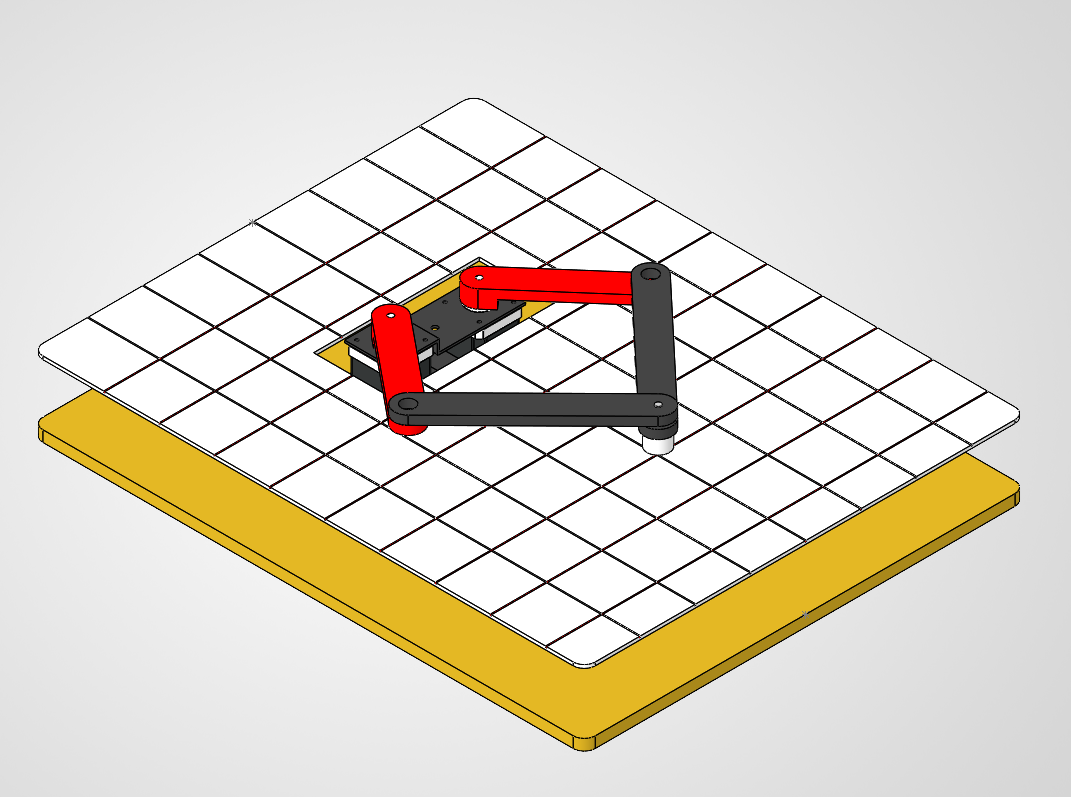
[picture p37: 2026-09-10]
MODEL/3dPRINT/MODEL PIC/Capture2.PNG

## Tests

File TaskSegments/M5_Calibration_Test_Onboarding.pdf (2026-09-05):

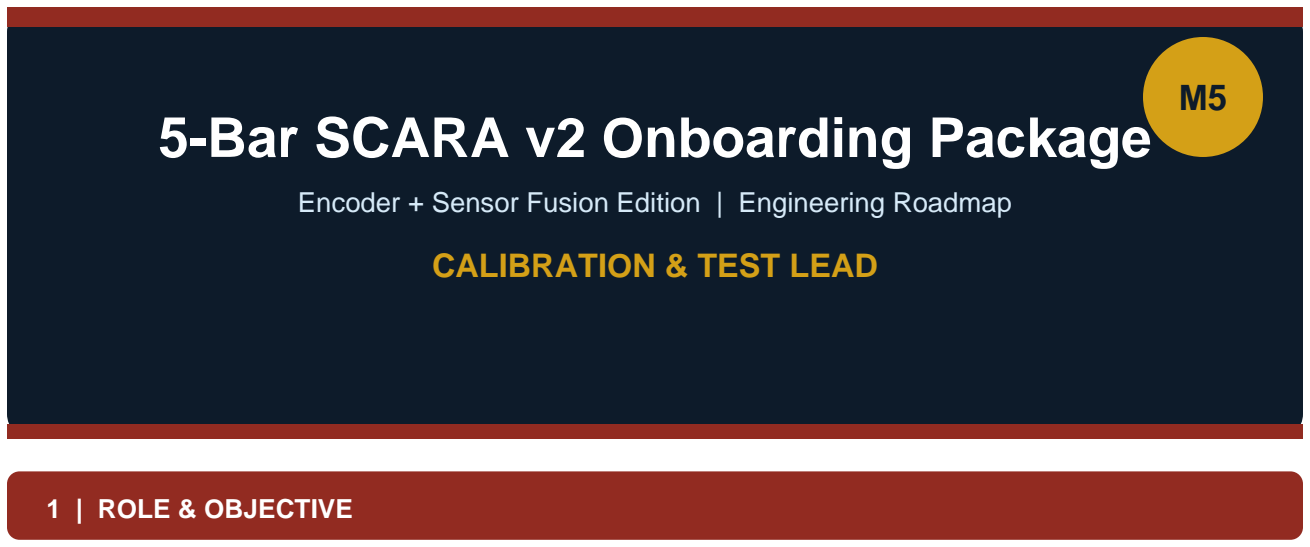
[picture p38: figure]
5-Bar SCARA v2 Onboarding Package; CALIBRATION & TEST LEAD; 1 | ROLE & OBJECTIVE

### Encoder + Sensor Fusion Edition | Engineering Roadmap

As Calibration & Test Lead (M5), you are the quality gate of the entire project. Nothing proceeds to the next phase without your documented sign-off. Your responsibilities span the full project lifecycle: you are the Reviewer for Phase 2B (encoder closed-loop) and Phase 3B (Kalman sensor fusion), and you co-own Phase 6 (robustness hardening and the 30-cycle unattended acceptance test).
Primary Mission: Design and execute rigorous verification protocols for each phase gate, harden the full system against real-world failure modes (lighting variation, stall events, power transients, Kalman divergence), and witness and certify the final 30-cycle acceptance run.

### 2 | HARDWARE & COMPONENTS REQUIRED

Component | Purpose | Notes
Dial Indicator (0.01mm resolution) | Phase 1 runout check; position accuracy measurement | Magnetic stand for hands-free setup
Oscilloscope / Logic Analyzer | Phase 1-D encoder signal quality; stall timing verification | Verify sub-1ms trigger response
Calibration Dot Grid (3×3) | Phase 3/3B centroid accuracy and RMS error measurement | Print flat on rigid surface
Reference Test Objects (colored) | Known-position targets for centroid and pick accuracy tests | 3–5 objects of different colors
Stopwatch / millis() Serial logging | Latency measurements: vision pipeline, correction loop | Arduino Serial Plotter preferred
Power Supply with current meter | Phase 6: monitor current during 30-cycle run for relay transients | Log power events
1000µF Electrolytic Capacitor | Phase 6 HW hardening: across DRV8825 VMot+/GND rail | Install per M5 power spec
100nF Ceramic Capacitors | Phase 6 HW hardening: DRV8825 VCC and encoder signal decoupling | 4+ per roadmap
Ferrite Bead (optional) | Phase 5/6: relay coil flyback suppression if encoder drift observed | On relay coil line

5-Bar SCARA v2 | M5 — Calibration & Test Lead | CONFIDENTIAL — Internal Use Only
Page 2 | 5-Bar Parallel SCARA — Onboarding Document | M5

### 3 | SOFTWARE & PLATFORMS REQUIRED

Tool | Purpose | Source
Python + numpy + pandas | Statistical analysis of test data: stddev, RMS, success rate | pip install
matplotlib / seaborn | Plot centroid noise, Kalman convergence, cycle time distribution | pip install
pyserial | Capture Serial output from both ESP32 nodes for automated logging | pip install pyserial
Arduino Serial Plotter | Real-time visualization of encoder counts and Kalman state | Built-in Arduino IDE
Spreadsheet (Excel / Sheets) | Track test results: PASS/FAIL per test ID, measured vs. target | Office / Google
Git | Access firmware branches; tag validated versions (e.g. v2B-PASSED) | git-scm.com
Test Log Template (create yours) | Standardized form: Test ID, date, tester, measured value, PASS/FAIL | Create from scratch

### 4 | AI INTEGRATION STRATEGY

Your role is analytical by nature. Use AI to generate test scripts, analyze statistical results, identify failure root causes, and design the 30-cycle acceptance protocol:

### Prompt 1 — Generate automated test script for TEST 2B-A:

"Write a Python script using pyserial to automate TEST 2B-A for an ESP32 encoder system. The script should: send a Serial command to move Motor 1 by +90 degrees, read the Serial response containing g_enc1_count, verify it equals ENC_CPR/4 (=600 counts), repeat 10 times, and report PASS if all within ±5 counts, FAIL otherwise. Include error handling for Serial timeout and connection loss."

### Prompt 2 — Analyze Kalman filter test results:

"I ran TEST 3B-A: 50 frames on a stationary object. Raw centroid X measurements (mm): [paste your 50 values]. Fused Kalman X output: [paste 50 values]. Calculate: (1) raw stddev, (2) fused stddev,
(3) improvement ratio, (4) does the filter meet the <1mm fused stddev spec? If not, suggest which Kalman parameter (Q_POS, Q_VEL, R_MEAS) to adjust and by how much."

### Prompt 3 — Design 30-cycle acceptance test protocol:

"Design a detailed test protocol for a 30-cycle unattended robotic pick-and-place run. Include: pre-run checklist, cycle timing log format, success/failure criteria per cycle, how to classify stall events vs. missed picks vs. drop errors, what data to log at each cycle, and the pass/fail final scoring rubric matching: PASS 1: >=27/30 successful cycles; PASS 2: zero unrecoverable faults; PASS 3: zero undetected stalls."

### Prompt 4 — Power hardening analysis:

"My SCARA robot uses a DRV8825 stepper driver, an electromagnet relay, and encoders all on the same power rail. During relay switching I see occasional encoder count drift (+/-3 counts). Explain the electrical cause and provide the exact capacitor and ferrite bead placement to eliminate this. What is the flyback voltage spike magnitude I should expect from an unprotected relay coil at 12V, and how does a flyback diode + ferrite bead suppress it?"

Page 3 | 5-Bar Parallel SCARA — Onboarding Document | M5

### 5 | BASIC ARCHITECTURE & CONNECTIONS

Phase You Review/Own | Input From | Your Gate Decision Affects
Phase 2B Reviewer | M2: encoder ISR, correction layer, stall detection firmware | M2 cannot proceed to Phase 4 without your sign-off
Phase 3B Reviewer | M3: Kalman filter, optical flow, occlusion handling firmware | M3 cannot contribute to Phase 4 without your sign-off
Phase 6 Co-Owner | M4+M2+M3+M1+M6: full integrated system | Final 30-cycle acceptance test; all members witness
Phase 5 Electromagnet Check | M4 integration: relay log + encoder position during pick/drop | Detect magnetic interference on encoder lines
Phase 6 Kalman Guard | M3: P[0][0] and P[1][1] covariance monitor | Divergence must be caught; reset logged
Phase 6 Power Hardening | M5 owns: capacitor installation, ferrite bead, ground return | Zero encoder drift during relay events required

Your Gate Authority: Every HARD GATE is your responsibility to document as PASSED. No team member advances without your written sign-off on the verification test log.

### 6 | TIMELINE & MILESTONES

[ DAY 1 ]
- Create master test log template: columns for Test ID, Date, Tester, Measured Value, Pass Threshold, Result
- Pre-read all verification tests: TEST 2B-A through 2B-E, TEST 3B-A through 3B-E
- Set up measurement rig: dial indicator, oscilloscope, calibration grid
- Install Python + pyserial + matplotlib for automated data capture

[ PHASE 2B REVIEW (Days ~6–8) ]
- TEST 2B-A: Command +90° on M1, confirm enc1_count = +600 counts (ENC_CPR/4)
- TEST 2B-B: Manually hold linkage during move; verify correction attempt triggers and logs
- TEST 2B-C: Block motor shaft for 600ms; verify FAULT state within 700ms
- TEST 2B-D: 10 pick positions; log encoder error each; all must be < ±1.5 deg
- TEST 2B-E: Idle 30 seconds; confirm encoder counts unchanged (zero drift)
- Document all results; countersign with M2; Phase 2B gate: PASS or BLOCKED

[ PHASE 3B REVIEW (Days ~9–11) ]
- TEST 3B-A: 50-frame stationary test; compute fused position stddev; must be < 1mm
- TEST 3B-B: Cover object for 3 frames; verify prediction within 5mm of truth
- TEST 3B-C: Move object at ~20mm/s; verify Vx/Vy sign and magnitude within 30%
- TEST 3B-D: Time full fusion pipeline (centroid + flow + Kalman); must be < 100ms
- TEST 3B-E: Remove object; verify no false transmit from noise
- Document all results; countersign with M3; Phase 3B gate: PASS or BLOCKED

[ PHASE 6 — ROBUSTNESS & ACCEPTANCE (Days ~14–16) ]
- Install power hardening: 1000µF across DRV8825 VMot, 100nF at VCC and encoder pins
- Run LED ring invariance check: TEST 3-B under LED ring only (ambient lights off)
- Verify Kalman divergence guard: force covariance spike; confirm reset logged

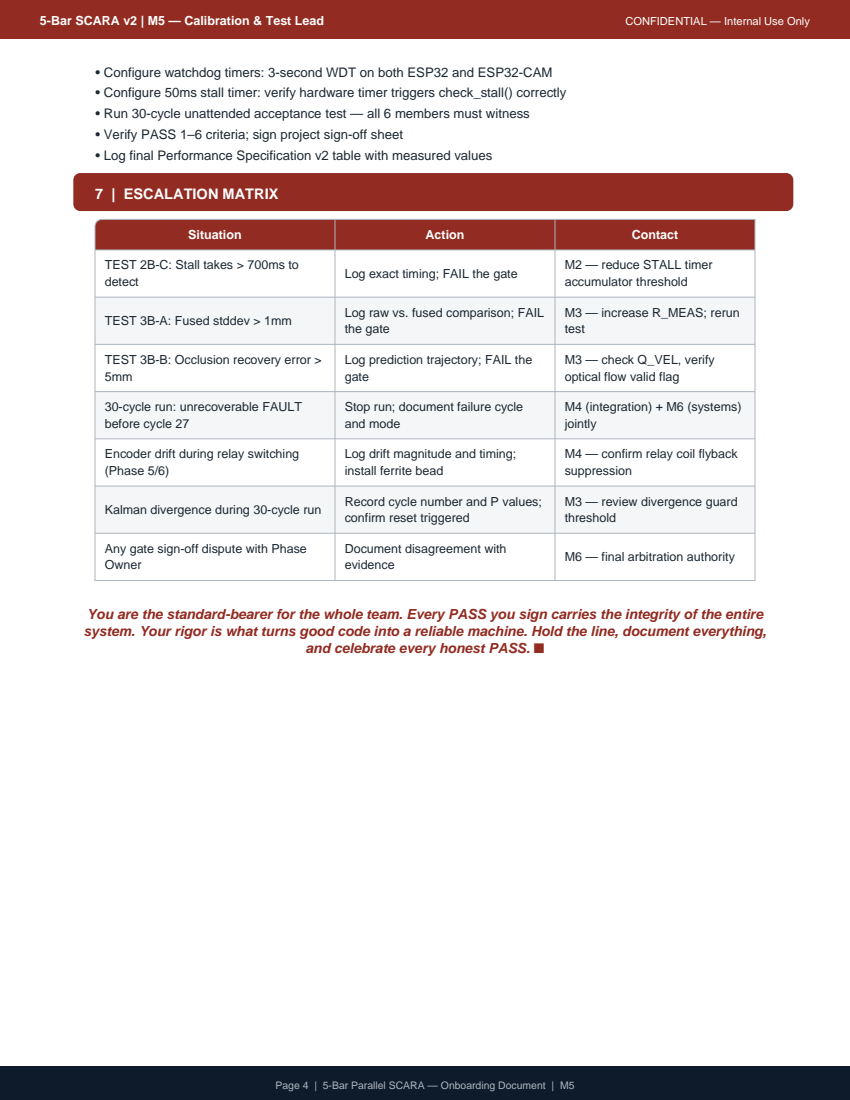
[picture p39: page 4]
7 | ESCALATION MATRIX

• Configure watchdog timers: 3-second WDT on both ESP32 and ESP32-CAM
• Configure 50ms stall timer: verify hardware timer triggers check_stall() correctly
• Run 30-cycle unattended acceptance test — all 6 members must witness
• Verify PASS 1–6 criteria; sign project sign-off sheet
• Log final Performance Specification v2 table with measured values

Situation | Action | Contact

TEST 2B-C: Stall takes > 700ms to detect | Log exact timing; FAIL the gate | M2 — reduce STALL timer accumulator threshold

TEST 3B-A: Fused stddev > 1mm | Log raw vs. fused comparison; FAIL the gate | M3 — increase R_MEAS; rerun test

TEST 3B-B: Occlusion recovery error > 5mm | Log prediction trajectory; FAIL the gate | M3 — check Q_VEL, verify optical flow valid flag

30-cycle run: unrecoverable FAULT before cycle 27 | Stop run; document failure cycle and mode | M4 (integration) + M6 (systems) jointly

Encoder drift during relay switching (Phase 5/6) | Log drift magnitude and timing; install ferrite bead | M4 — confirm relay coil flyback suppression

Kalman divergence during 30-cycle run | Record cycle number and P values; confirm reset triggered | M3 — review divergence guard threshold

Any gate sign-off dispute with Phase Owner | Document disagreement with evidence | M6 — final arbitration authority

You are the standard-bearer for the whole team. Every PASS you sign carries the integrity of the entire
system. Your rigor is what turns good code into a reliable machine. Hold the line, document everything,

and celebrate every honest PASS. ■

Page 4 | 5-Bar Parallel SCARA — Onboarding Document | M5

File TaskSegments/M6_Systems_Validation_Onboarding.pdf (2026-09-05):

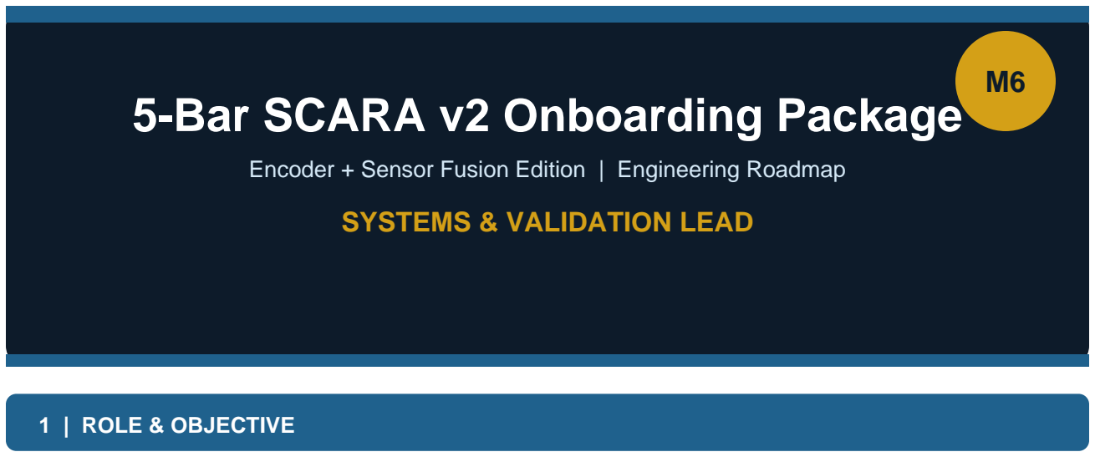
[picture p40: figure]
5-Bar SCARA v2 Onboarding Package; SYSTEMS & VALIDATION LEAD; 1 | ROLE & OBJECTIVE

### Encoder + Sensor Fusion Edition | Engineering Roadmap

As Systems & Validation Lead (M6), you have the widest scope on the team. You own the Pre-Phase baseline audit — establishing the verified Git foundation before any code changes — and you co-own Phase 6 with M5, delivering the watchdog timer configuration, the final performance specification documentation, and overseeing the 30-cycle acceptance test. Between those bookends, you serve as support in Phase 5 and as the team's escalation authority and cross-team integrator.
Primary Mission: Create a clean, documented baseline that every other member can build upon; configure system-level fault protection (WDT, stall timer); author the final performance specification; and ensure the project closes with a signed, witnessed 30-cycle acceptance test.

### 2 | HARDWARE & COMPONENTS REQUIRED

Component | Purpose | Notes
Both ESP32 + ESP32-CAM boards | Pre-Phase: verify existing firmware runs before any modification | Flash and test BEFORE any member modifies code
Full wiring harness (as-built) | Pre-Phase: photograph and label every wire; create GPIO pin table | Critical for rollback if v2 changes cause faults
Git repository (remote + local) | Version control custodian; tag v0.0-baseline before Day 2 | GitHub / GitLab; enforce branch protection
USB-to-Serial adapter | Flash and Serial-monitor both nodes during baseline verification | 2 adapters recommended
Physical alignment tape/marker | Mark world-frame origin and home position before M1 modifies frame | Photographed and documented in baseline
Oscilloscope (borrowed from M5) | WDT and stall timer verification in Phase 6 | Verify 50ms timer period
Documentation tools (laptop) | Write performance spec table; author sign-off sheet; maintain test log master | Shared Google Doc or Confluence recommended

### 3 | SOFTWARE & PLATFORMS REQUIRED

5-Bar SCARA v2 | M6 — Systems & Validation Lead | CONFIDENTIAL — Internal Use Only
Page 2 | 5-Bar Parallel SCARA — Onboarding Document | M6
Tool | Purpose | Source
Git (CLI + GitHub Desktop) | Create v0.0-baseline tag; manage branches; resolve merge conflicts | git-scm.com
Arduino IDE 2.x / PlatformIO | Flash and verify baseline firmware on both nodes | arduino.cc
config.h editor (VSCode) | Create config.h skeleton with encoder PPR field placeholder | code.visualstudio.com
Markdown editor (Typora / VSCode) | Write pre-phase audit report, performance spec, sign-off sheet | typora.io
Python + pandas | Aggregate test logs from M5; generate final performance table | pip install pandas
Spreadsheet | GPIO pin table; Phase 0 audit checklist; performance spec matrix | Excel / Google Sheets
Camera (smartphone) | Photograph wiring harness, GPIO table, world-frame origin marker | Any smartphone

### 4 | AI INTEGRATION STRATEGY

Your work is systems-level: documentation quality, configuration management, and fault-protection code. Use AI to generate audit templates, WDT configuration, and final specification documents:

### Prompt 1 — Generate GPIO audit table:

"I have an ESP32 connected to: DRV8825 stepper driver (STEP, DIR, ENABLE pins), encoder 1 (A, B channels on interrupt-capable pins), encoder 2 (A, B channels), ESP-NOW (WiFi, no extra GPIO), relay module (digital output), and UART Serial. Create a complete GPIO pin assignment table showing: GPIO number, function, direction (IN/OUT), interrupt-capable (Y/N), and notes on constraints. Flag any conflicts or pins that cannot be used as interrupts on ESP32."

### Prompt 2 — Watchdog timer configuration:

"I need to configure esp_task_wdt on an ESP32 Arduino project for a robot pick-and-place system. The WDT timeout should be 3 seconds. I also need a hardware timer ISR at 50ms for stall detection. Provide: (1) complete WDT init code with esp_task_wdt_init, esp_task_wdt_add, and esp_task_wdt_reset placement, (2) hardware timer setup with timerBegin/timerAttachInterrupt/timerAlarmWrite for 50ms, (3) explain what happens if WDT fires and how to recover."

### Prompt 3 — Performance specification template:

"Generate a professional performance specification table for a robotics project with these parameters: Vision pipeline latency (target <100ms), ESP-NOW latency (target <15ms), IK solve time (target <1ms), Encoder correction latency (target <200ms), Stall detection response (target <700ms), Kalman position noise stddev (target <1mm), Pick success rate (target >=93%), Packet loss rate (target <2%), Full cycle time (target <9s). Format as a formal table with columns: Parameter |
Target | Measured | Pass/Fail. Include a project sign-off block at the bottom with signature lines
for 6 team members."

### Prompt 4 — Git branching strategy for the team:

"We have 6 team members working on a microcontroller firmware project with 2 firmware projects (kinematic node and vision node). We need: feature branches per phase, hard gate merges only after PASS sign-off, version tags at each phase completion, and protection of the main branch. Design a Git branching strategy and naming convention. Include the exact git commands to create the v0.0-baseline tag, create a feature branch, and merge after gate PASS."

Page 3 | 5-Bar Parallel SCARA — Onboarding Document | M6

### 5 | BASIC ARCHITECTURE & CONNECTIONS

Your Deliverable | Who Depends On It | Dependency Type
v0.0-baseline Git tag + config.h skeleton | ALL 6 MEMBERS | Every member starts from this baseline — BLOCKING
GPIO pin table (4 encoder pins reserved) | M1 (mounting) + M2 (ISR) | Wrong pin = ISR fails silently; CRITICAL
World-frame origin photograph + marker | M1 (measurements) + M4 (calibration) | IK coordinate reference; must precede Phase 1
Pre-Phase PASS confirmation to M2 | M2 cannot begin Phase 2 until M6 signs Pre-Phase PASS | Hard gate; no exceptions
WDT configuration (Phase 6) | Both ESP32 nodes (M2 + M3 firmware) | System-level fault protection for unattended run
Performance Spec v2 final table | M5 + all members (sign-off sheet) | Project closure documentation; required for sign-off
Escalation arbitration | Any member blocked by inter-team dispute | Authority to override if deadlocked

Your Scope: Pre-Phase → [all phases run] → Phase 5 Support (integration observer) → Phase 6: WDT + hardware hardening → 30-cycle acceptance → Performance Spec → Sign-off

### 6 | TIMELINE & MILESTONES

[ DAY 1 — PRE-PHASE (CRITICAL PATH) ]
- Record ALL existing AccelStepper maxSpeed() and setAcceleration() values from current firmware
- Photograph full wiring harness — label every wire with GPIO number and function
- Create GPIO pin table: identify which 4 interrupt-capable pins are reserved for encoders
- Verify recommended encoder GPIO: 34 (ENC1_A), 35 (ENC1_B), 36 (ENC2_A), 39 (ENC2_B)
- Create config.h skeleton with ENCODER_PPR placeholder; commit to Git
- Tag current codebase: git tag v0.0-baseline && git push origin v0.0-baseline
- Confirm M2 verifies robot moves under existing firmware — obtain M2 sign-off
- Pre-Phase PASS criteria: baseline tagged, 4 GPIO reserved, M2 confirms movement

[ DAYS 2–13 (Monitor & Support Role) ]
- Attend daily standups; track each phase's gate status on master checklist
- Resolve any Git merge conflicts or config.h update disputes immediately
- Phase 5 Support: be present during integration; assist M4 with calibration logistics
- Maintain master test log: collect M5's signed test results after each phase gate
- Flag to all members if any HARD GATE is at risk of blocking downstream phases

[ DAYS 14–16 — PHASE 6 CO-OWNERSHIP ]
- Configure WDT on ESP32 (kinematic): esp_task_wdt_init(3, true) + reset in main loop
- Configure WDT on ESP32-CAM (vision): same 3-second WDT around camera loop
- Verify 50ms hardware stall timer: timerBegin + timerAttachInterrupt + timerAlarmWrite
- Oversee M5's power hardening: 1000µF DRV8825, 100nF VCC and encoder, ferrite bead
- Author Performance Specification v2 table: all parameters with measured values from M5's logs

Page 4 | 5-Bar Parallel SCARA — Onboarding Document | M6
- Coordinate 30-cycle acceptance test scheduling — all 6 members must be present
- Witness 30-cycle run; document each cycle outcome (success/fail/stall/occlusion)
- Confirm PASS 1–6 criteria met; circulate sign-off sheet; collect all 6 signatures

### 7 | ESCALATION MATRIX

You ARE the top-level escalation point. Below are the situations where you should proactively intervene, and your recommended actions:

Situation | Your Action | Timeframe
Pre-Phase: any member starts modifying code before baseline is tagged | Stop modification immediately; complete baseline first | Day 1 — BLOCKING
Phase gate claimed PASSED without M5 written sign-off | Reject advancement; request documented test log | Immediate
Phase 2B and 3B both delayed: Phase 4 at risk | Re-prioritize team capacity; identify if parallel work is possible | Flag by Day 8
Inter-member dispute on config.h values or packet format | Arbitrate: use original spec + AI validation; make final call | Within 24 hours
30-cycle run fails PASS 2 (unrecoverable fault) | Document failure; do NOT re-run without root cause fix | Immediate stop
WDT fires during integration testing | Log stack trace; coordinate M2/M3 fix; verify reset recovery | Before Phase 6 acceptance
Any member unavailable for phase gate review | Assign temporary reviewer from remaining team with M6 oversight | Day of gap

You set the foundation everyone builds on and close the loop everyone depends on. The team's success starts with your Day 1 baseline commit and ends with your Phase 6 sign-off. Lead with clarity, enforce the gates, and drive the team home. ■

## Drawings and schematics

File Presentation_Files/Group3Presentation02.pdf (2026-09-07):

# Vision Guided Parallel SCARA for

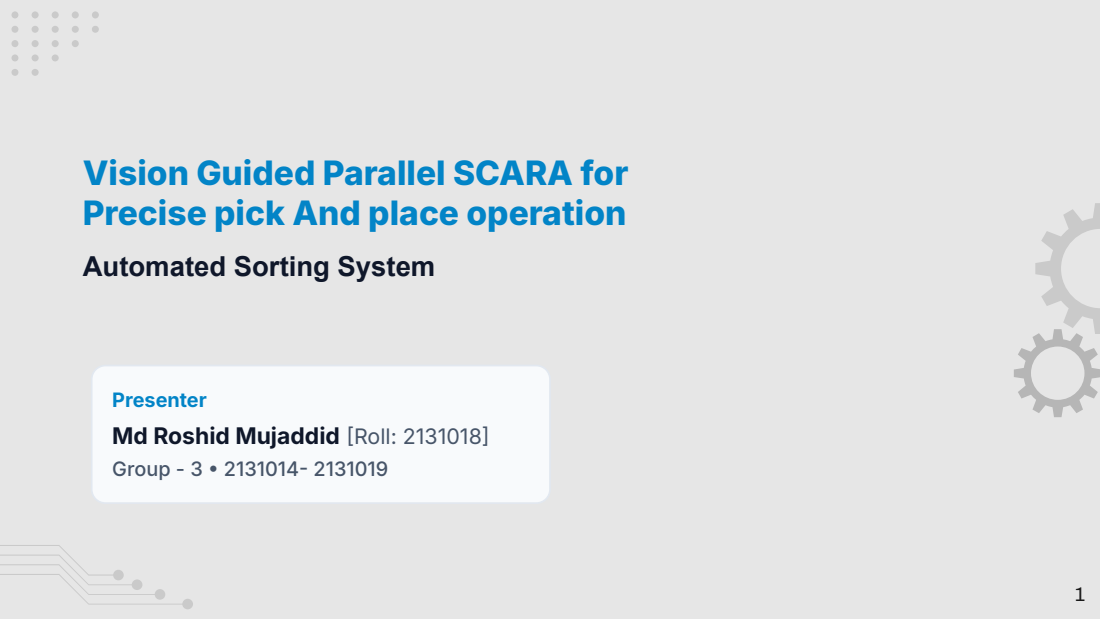
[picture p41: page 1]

Precise pick And place operation

Automated Sorting System

Presenter
Md Roshid Mujaddid Roll: 2131018
Group - 3 2131014 2131019

# Project Roles

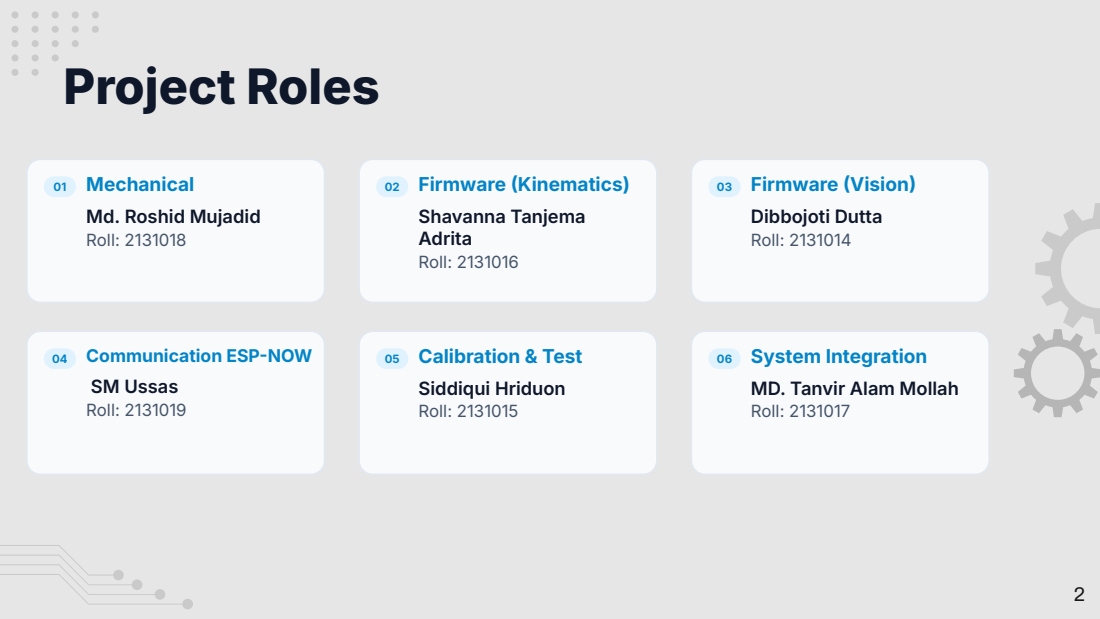
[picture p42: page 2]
02 Firmware Kinematics) Shavanna Tanjema Adrita Roll: 2131016; 03 Firmware Vision Dibbojoti Dutta Roll: 2131014; 05 Calibration & Test Siddiqui Hriduon Roll: 2131015

01 Mechanical
Md. Roshid Mujadid
Roll: 2131018

04 Communication ESPNOW
SM Ussas
Roll: 2131019

06 System Integration
MD. Tanvir Alam Mollah
Roll: 2131017

# Mechanical

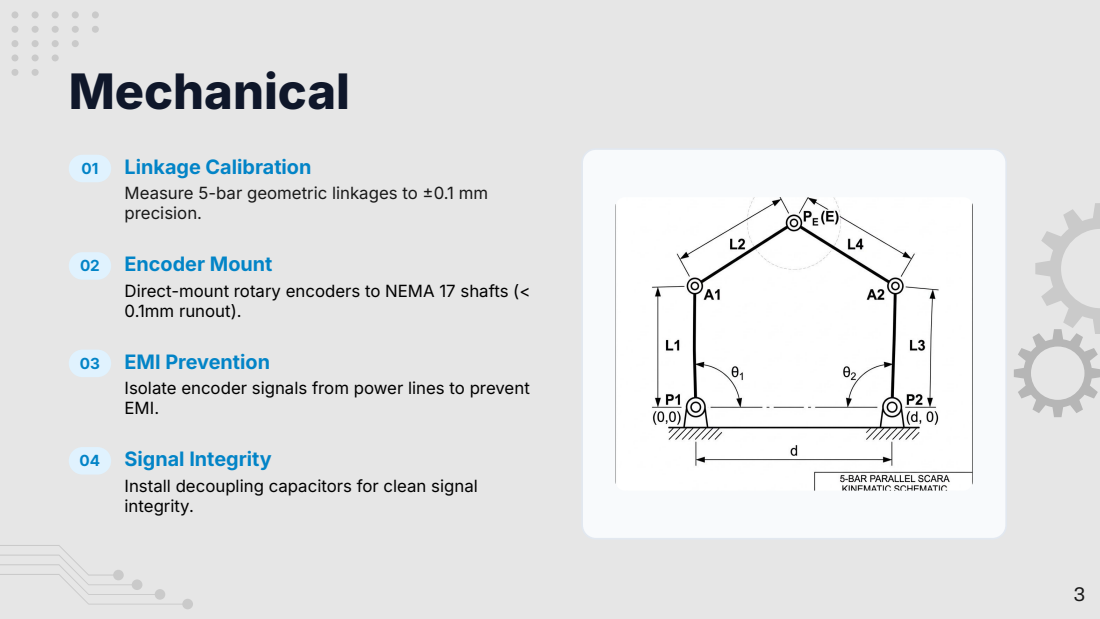
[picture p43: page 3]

01 Linkage Calibration
Measure 5-bar geometric linkages to 0.1 mm
precision.

02 Encoder Mount
Direct-mount rotary encoders to NEMA 17 shafts (<
0.1mm runout).

03 EMI Prevention
Isolate encoder signals from power lines to prevent
EMI.

04 Signal Integrity
Install decoupling capacitors for clean signal
integrity.

# Firmware Kinematics)

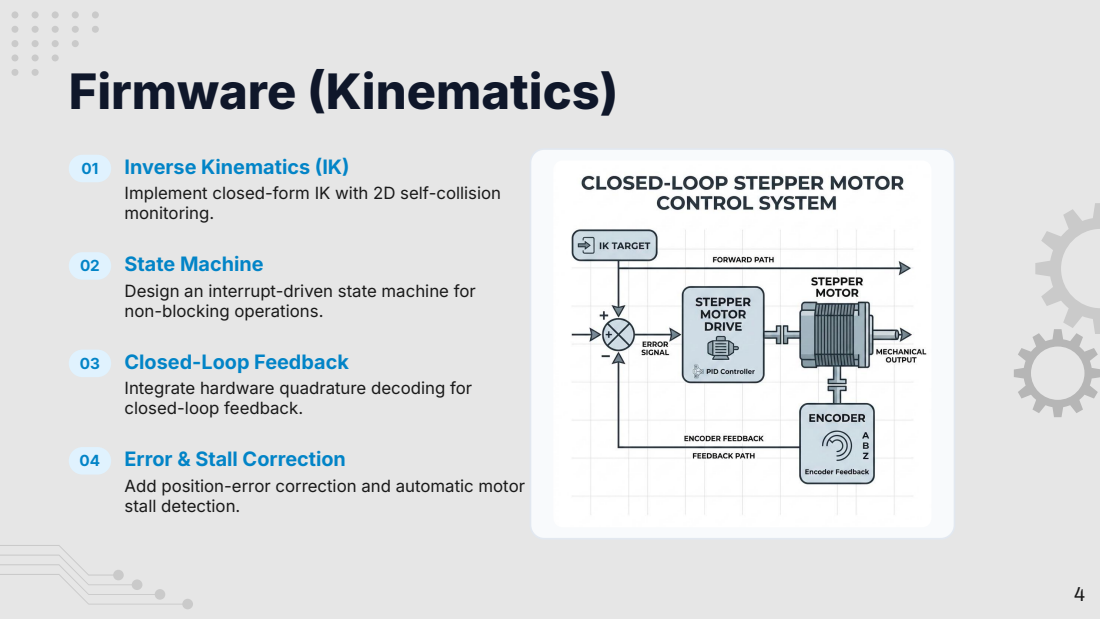
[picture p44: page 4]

01 Inverse Kinematics IK
Implement closed-form IK with 2D self-collision
monitoring.

02 State Machine
Design an interrupt-driven state machine for
non-blocking operations.

03 Closed-Loop Feedback
Integrate hardware quadrature decoding for
closed-loop feedback.

04 Error & Stall Correction
Add position-error correction and automatic motor
stall detection.

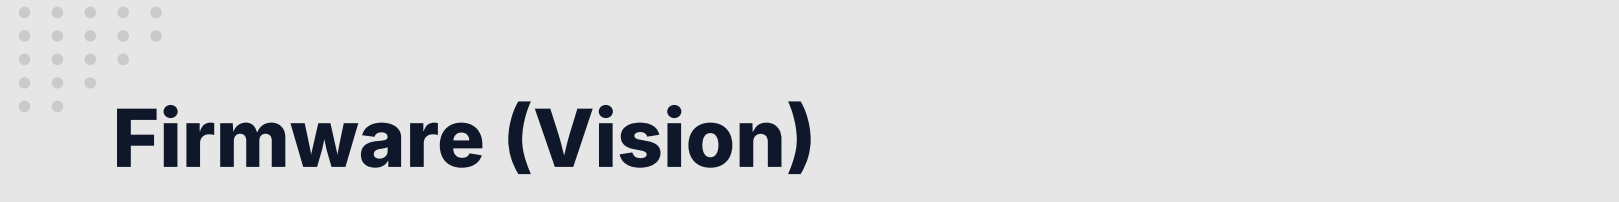
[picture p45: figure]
Firmware Vision
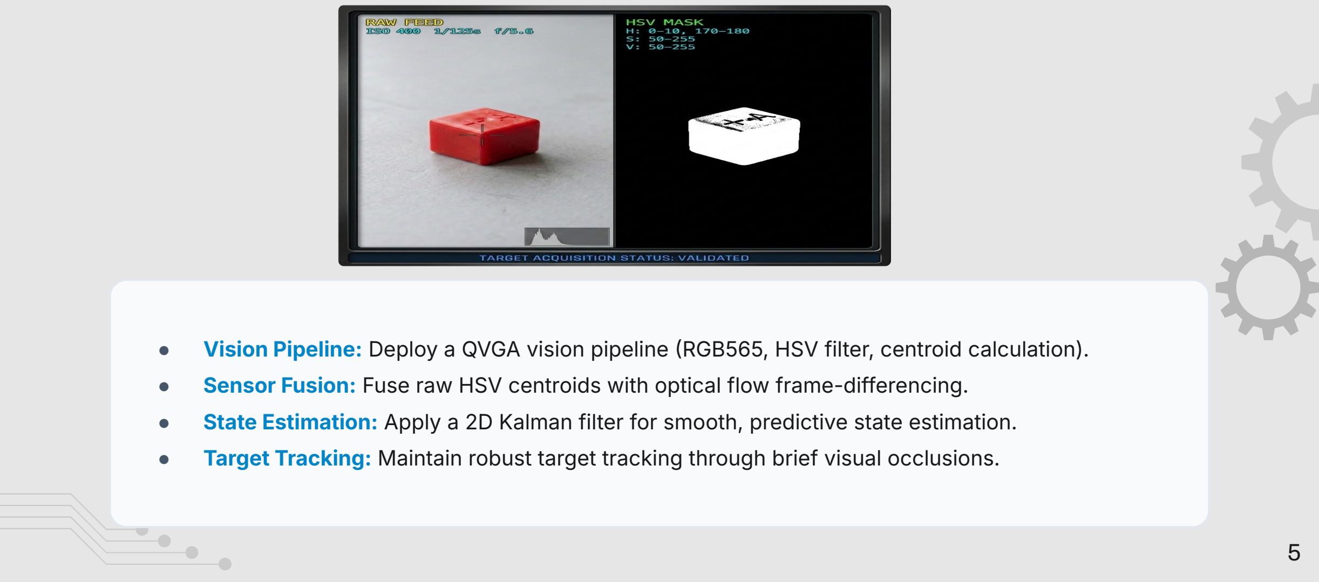
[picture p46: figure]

- Vision Pipeline: Deploy a QVGA vision pipeline RGB565, HSV filter, centroid calculation).
- Sensor Fusion: Fuse raw HSV centroids with optical flow frame-differencing.
- State Estimation: Apply a 2D Kalman filter for smooth, predictive state estimation.
- Target Tracking: Maintain robust target tracking through brief visual occlusions.

# Communication ESPNOW

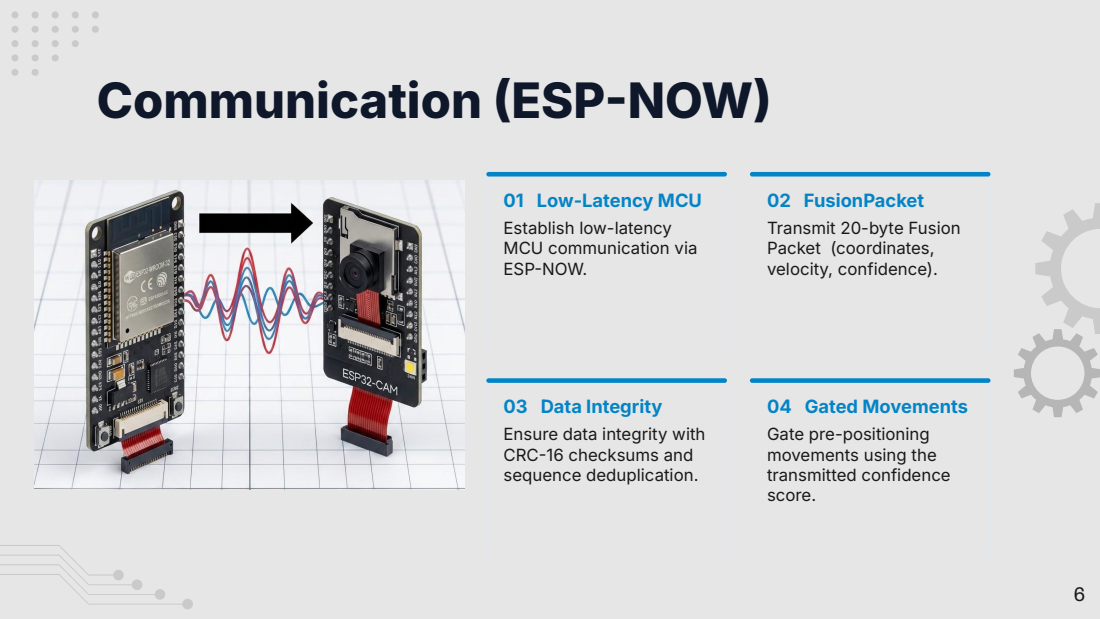
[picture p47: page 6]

01 Low-Latency MCU
Establish low-latency
MCU communication via
ESPNOW.

02 FusionPacket
Transmit 20-byte Fusion
Packet (coordinates,
velocity, confidence).

03 Data Integrity
Ensure data integrity with
CRC16 checksums and
sequence deduplication.

04 Gated Movements
Gate pre-positioning
movements using the
transmitted confidence
score.

# Calibration & Validation Infographic

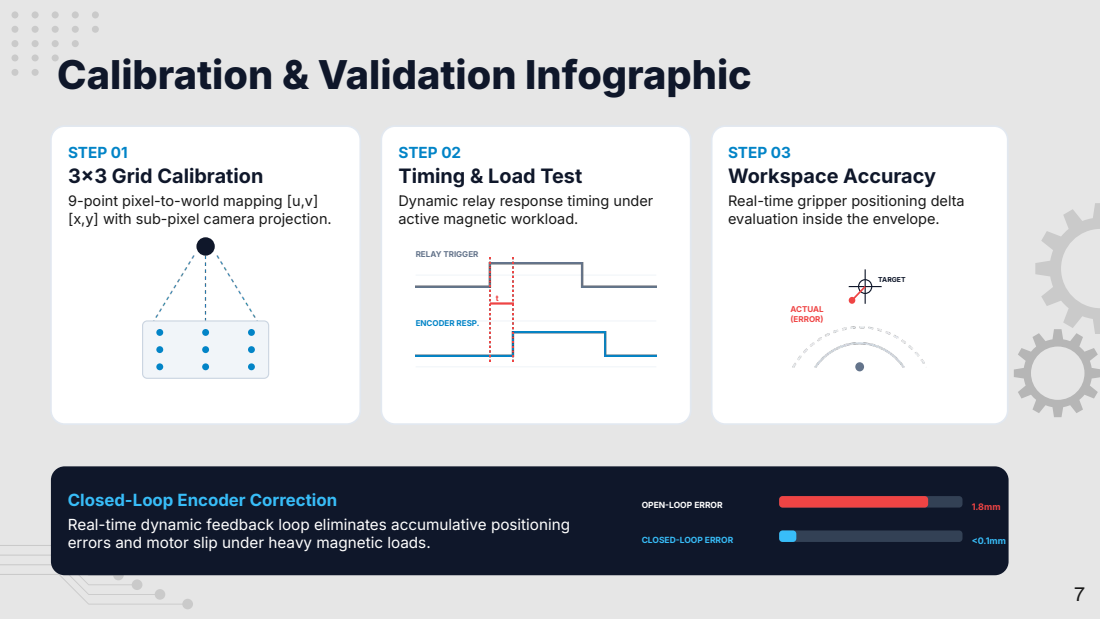
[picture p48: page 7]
RELAY TRIGGER; ENCODER RESP.; TARGET; ACTUAL ERROR; OPENLOOP ERROR; CLOSEDLOOP ERROR

STEP 01
33 Grid Calibration
9-point pixel-to-world mapping [u,v]
[x,y] with sub-pixel camera projection.

STEP 02
Timing & Load Test
Dynamic relay response timing under
active magnetic workload.

STEP 03
Workspace Accuracy
Real-time gripper positioning delta
evaluation inside the envelope.

Closed-Loop Encoder Correction
Real-time dynamic feedback loop eliminates accumulative positioning
errors and motor slip under heavy magnetic loads.

# System Integration & Validation

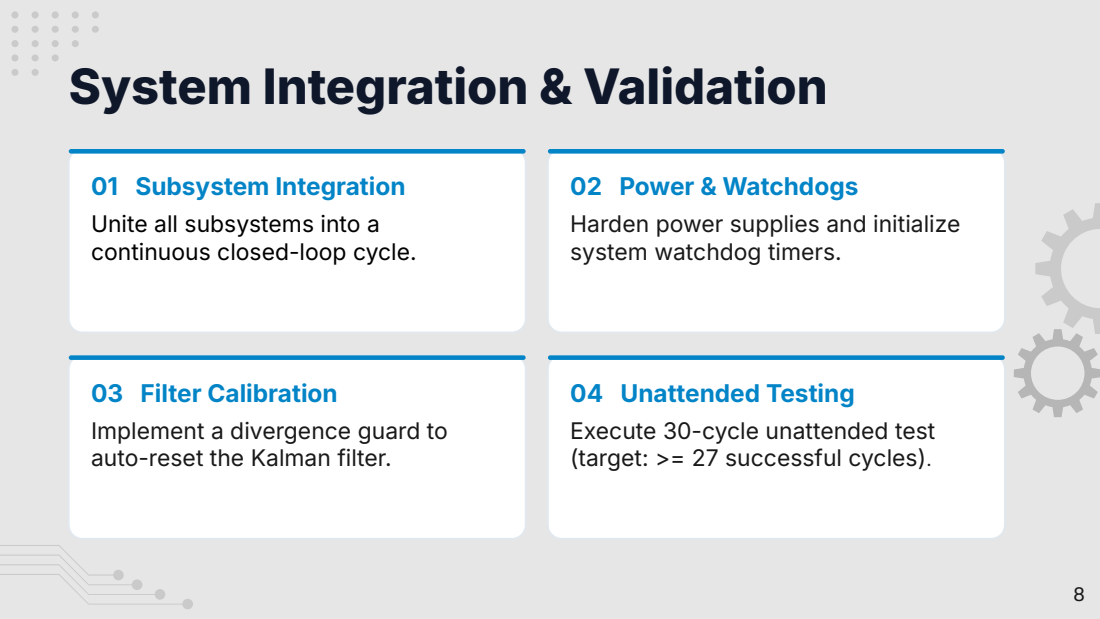
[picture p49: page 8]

01 Subsystem Integration
Unite all subsystems into a
continuous closed-loop cycle.

02 Power & Watchdogs
Harden power supplies and initialize
system watchdog timers.

03 Filter Calibration
Implement a divergence guard to
auto-reset the Kalman filter.

04 Unattended Testing
Execute 30-cycle unattended test
(target: >= 27 successful cycles).

# Project Timeline Weeks 713

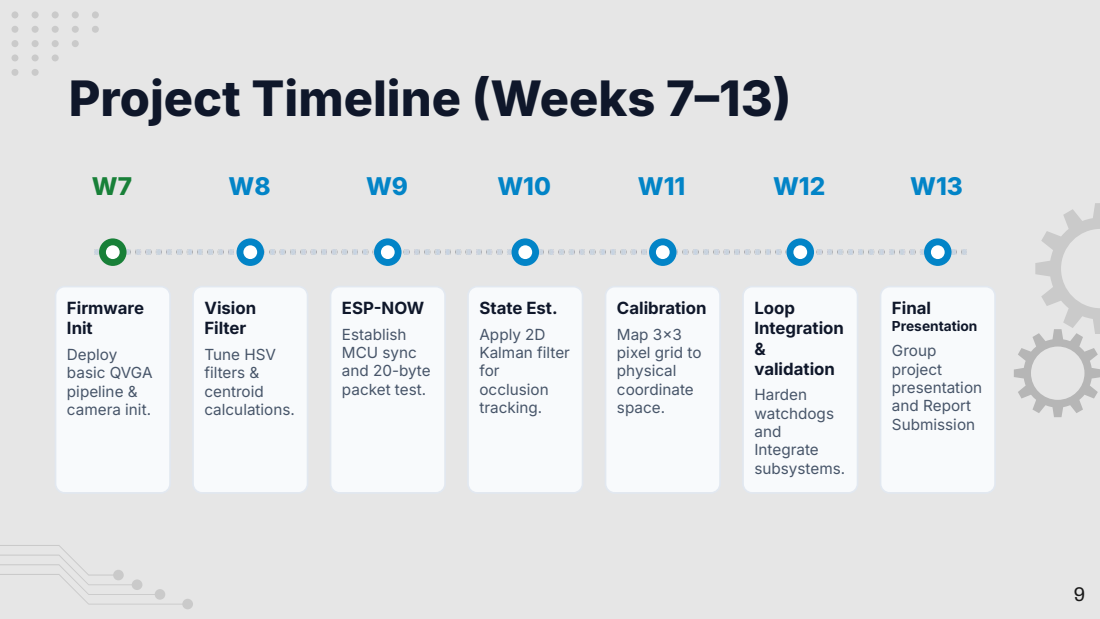
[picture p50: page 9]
Firmware Init Deploy basic QVGA pipeline & camera init.; Vision Filter Tune HSV filters & centroid calculations.; ESPNOW Establish MCU sync and 20-byte packet test.; State Est. Apply 2D Kalman filter for occlusion tracking.; Calibration Map 33 pixel grid to physical coordinate space.; Loop Integration & validation Harden watchdogs and Integrate subsystems.; Final Presentation Group project presentation and Report Submission

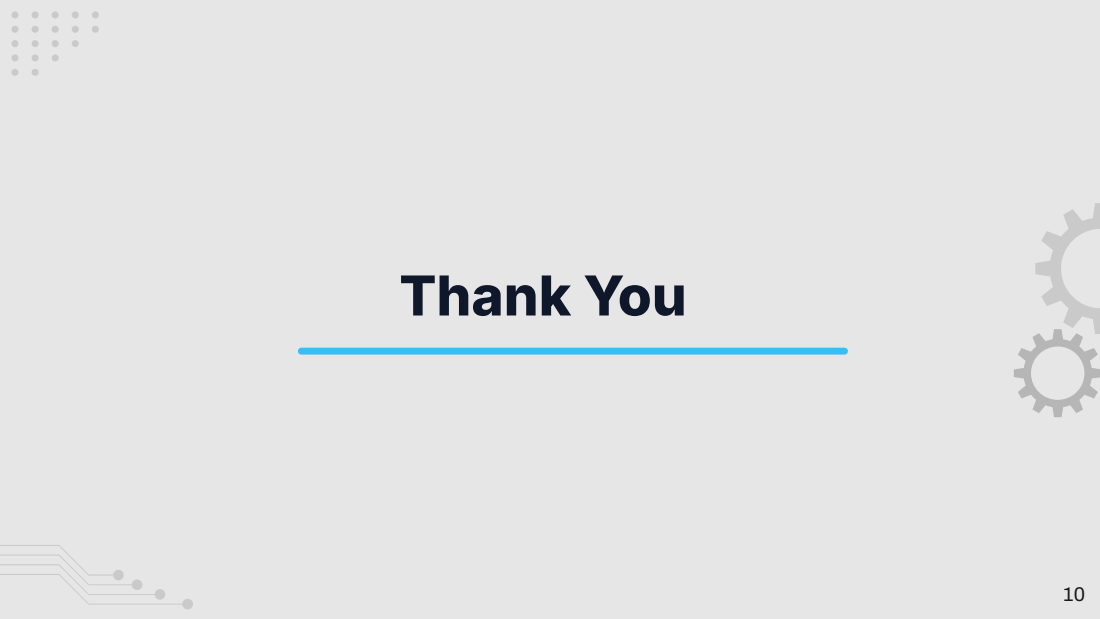
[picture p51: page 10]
Thank You

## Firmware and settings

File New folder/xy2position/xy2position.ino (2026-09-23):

#include <Arduino.h>
#include <FastAccelStepper.h>
#include <math.h>

// -----------------------------------------------------------------------------
// Pin Allocations for ESP32 DevKit V1 and DRV8825 Drivers
// -----------------------------------------------------------------------------
#define MOTOR1_STEP_PIN    18
#define MOTOR1_DIR_PIN     19
#define MOTOR2_STEP_PIN    22
#define MOTOR2_DIR_PIN     23
#define SHARED_ENABLE_PIN  21

// -----------------------------------------------------------------------------
// Physical Arm Parameters and Kinematic Constants
// -----------------------------------------------------------------------------
const double BASE1_X = -40.0; 
const double BASE1_Y =   0.0; 
const double BASE2_X =  40.0; 
const double BASE2_Y =   0.0; 

const double LINK1 = 110.0;   
const double LINK2 = 110.0;   
const double LINK3 = 160.0;   
const double LINK4 = 160.0;   

// Stepper Configuration (1/32 microstepping: 200 * 32 = 6400 steps/rev)
const double STEPS_PER_REV = 6400.0;
const double STEPS_PER_RAD = STEPS_PER_REV / (2.0 * M_PI);

FastAccelStepperEngine engine = FastAccelStepperEngine();
FastAccelStepper *stepper1 = NULL;
FastAccelStepper *stepper2 = NULL;

// Function prototype for IK
bool solveInverseKinematics(double x, double y, double &out_theta1, double &out_theta2);

void setup() {
  Serial.begin(115200);
  while (!Serial && millis() < 2000) { delay(10); }

  Serial.println(F("=================================================="));
  Serial.println(F(" CARTESIAN (X,Y) CONTROL MODE WITH IK"));
  Serial.println(F("=================================================="));

  engine.init();
  stepper1 = engine.stepperConnectToPin(MOTOR1_STEP_PIN);
  stepper2 = engine.stepperConnectToPin(MOTOR2_STEP_PIN);

  if (!stepper1 || !stepper2) {
    Serial.println(F("[ERROR] Hardware Timer Allocation Failed!"));
    while (true) { delay(1000); }
  }

  // --- MOTOR 1 CONFIGURATION ---
  stepper1->setDirectionPin(MOTOR1_DIR_PIN, false);
  stepper1->setEnablePin(SHARED_ENABLE_PIN, true); // true = active LOW for DRV8825
  stepper1->setAutoEnable(true);                   // Energizes coils ONLY when moving
  stepper1->setDelayToEnable(30);                  // 30ms warm-up to establish flux before first step
  stepper1->setDelayToDisable(500);                // 500ms post-move holding before cutting current
  stepper1->setSpeedInHz(3200); 
  stepper1->setAcceleration(2000);

  // --- MOTOR 2 CONFIGURATION ---
  stepper2->setDirectionPin(MOTOR2_DIR_PIN, false);
  stepper2->setEnablePin(SHARED_ENABLE_PIN, true); // true = active LOW for DRV8825
  stepper2->setAutoEnable(true);                   // Energizes coils ONLY when moving
  stepper2->setDelayToEnable(30);                  // 30ms warm-up to establish flux before first step
  stepper2->setDelayToDisable(500);                // 500ms post-move holding before cutting current
  stepper2->setSpeedInHz(3200); 
  stepper2->setAcceleration(2000);

  // Set home position (90 degrees vertical = 1,600 steps)
  stepper1->setCurrentPosition(1600);
  stepper2->setCurrentPosition(1600);

  Serial.println(F("[READY] Arms calibrated to initial 90-degree position."));
  Serial.println(F("Drivers will remain cool at rest (AutoEnable active)."));
  Serial.println(F("Enter Target Coordinates in mm: [X] [Y] (e.g., 0 200)"));
  Serial.println(F("--------------------------------------------------"));
}

void loop() {
  if (Serial.available() > 0) {
    // Read the X and Y inputs
    float targetX = Serial.parseFloat();
    float targetY = Serial.parseFloat();

    // Flush trailing characters/newlines from serial buffer
    while (Serial.available() > 0) {
      Serial.read();
      delay(2);
    }

    Serial.printf("\nCommand Received: Move to X = %.1f mm, Y = %.1f mm\n", targetX, targetY);

    double theta1_rad = 0.0;
    double theta2_rad = 0.0;

    // Run the Inverse Kinematics Math
    if (solveInverseKinematics(targetX, targetY, theta1_rad, theta2_rad)) {
      
      // Convert radians to steps
      int32_t targetSteps1 = round(theta1_rad * STEPS_PER_RAD);
      int32_t targetSteps2 = round(theta2_rad * STEPS_PER_RAD);

      // Print computed angles
      double deg1 = theta1_rad * (180.0 / M_PI);
      double deg2 = theta2_rad * (180.0 / M_PI);
      Serial.printf("[IK SUCCESS] Joint Angles: Theta1 = %.2f deg, Theta2 = %.2f deg\n", deg1, deg2);

      // Execute movement
      stepper1->moveTo(targetSteps1);
      stepper2->moveTo(targetSteps2);

      // Wait for movement to finish
      while (stepper1->isRunning() || stepper2->isRunning()) {
        vTaskDelay(1 / portTICK_PERIOD_MS); 
      }

      Serial.println(F("Move Complete. Entering low-power rest..."));
    } else {
      Serial.println(F("[IK ERROR] Target coordinate is outside physical reach!"));
    }
    Serial.println(F("--------------------------------------------------"));
  }
}

// -----------------------------------------------------------------------------
// Real-Time Inverse Kinematics Implementation
// -----------------------------------------------------------------------------
bool solveInverseKinematics(double x, double y, double &out_theta1, double &out_theta2) {
  // Delta distance components from base joints to target coordinate
  double dx1 = x - BASE1_X;
  double dy1 = y - BASE1_Y;
  double dx2 = x - BASE2_X;
  double dy2 = y - BASE2_Y;

  // Linear Euclidean spans from base points to target
  double D1 = hypot(dx1, dy1);
  double D2 = hypot(dx2, dy2);

  // Boundary check against link extension envelope constraints
  if (D1 > (LINK1 + LINK3) || D1 < fabs(LINK1 - LINK3) ||
      D2 > (LINK2 + LINK4) || D2 < fabs(LINK2 - LINK4)) {
    return false; // Point lies outside kinematic workspace reach
  }

  // Angular orientations of linear distance vectors
  double alpha1 = atan2(dy1, dx1);
  double alpha2 = atan2(dy2, dx2);

  // Cosine rule triangle interior angle calculations
  double cos_beta1 = constrain((LINK1 * LINK1 + D1 * D1 - LINK3 * LINK3) / (2.0 * LINK1 * D1), -1.0, 1.0);
  double cos_beta2 = constrain((LINK2 * LINK2 + D2 * D2 - LINK4 * LINK4) / (2.0 * LINK2 * D2), -1.0, 1.0);

  double beta1 = acos(cos_beta1);
  double beta2 = acos(cos_beta2);

  // Outer branch kinematic combination ("elbow-up" configuration)
  out_theta1 = alpha1 + beta1;
  out_theta2 = alpha2 - beta2;

  return true;
}

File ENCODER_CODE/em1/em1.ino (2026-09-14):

// Single Motor Single ENCODER
#include <Arduino.h>
#include <FastAccelStepper.h>
#include <Wire.h>

// --- Pins for Motor 1 & Encoder 1 ---
#define MOTOR_STEP_PIN    18
#define MOTOR_DIR_PIN     19
#define ENABLE_PIN        21
#define ENCODER_SDA       32  // Updated to match your wiring
#define ENCODER_SCL       33  // Updated to match your wiring

// --- Objects ---
TwoWire I2C_Encoder = TwoWire(0);
const int AS5600_ADDRESS = 0x36; 
const int RAW_ANGLE_REGISTER = 0x0C; 

FastAccelStepperEngine engine = FastAccelStepperEngine();
FastAccelStepper *stepper = NULL;

// --- Global Variable ---
int startingOffset = 0; // Treats startup position as 0

// --- Functions ---
uint16_t readEncoder() {
  I2C_Encoder.beginTransmission(AS5600_ADDRESS);
  I2C_Encoder.write(RAW_ANGLE_REGISTER);
  I2C_Encoder.endTransmission(false);
  I2C_Encoder.requestFrom(AS5600_ADDRESS, 2);
  if (I2C_Encoder.available() == 2) {
    uint8_t highByte = I2C_Encoder.read();
    uint8_t lowByte = I2C_Encoder.read();
    return ((highByte << 8) | lowByte) & 0x0FFF; 
  }
  return 0; 
}

int getZeroedTicks() {
  int rawTicks = readEncoder();
  // Subtract startup offset, add 4096 to prevent negative math, wrap at 4096
  return (rawTicks - startingOffset + 4096) % 4096; 
}

void setup() {
  Serial.begin(115200);
  
  // 1. Initialize Encoder
  I2C_Encoder.begin(ENCODER_SDA, ENCODER_SCL, 400000); 
  delay(500); // Let sensor boot up
  
  // Record current physical position as "0"
  startingOffset = readEncoder();
  
  // 2. Initialize Stepper
  pinMode(ENABLE_PIN, OUTPUT);
  digitalWrite(ENABLE_PIN, LOW); 

  engine.init();
  stepper = engine.stepperConnectToPin(MOTOR_STEP_PIN);
  stepper->setDirectionPin(MOTOR_DIR_PIN, true); // Try changing to 'true' if direction is backwards
  stepper->setSpeedInHz(3200); 
  stepper->setAcceleration(2000);
  
  Serial.println("========================================");
  Serial.println("Single Motor Encoder Test Ready.");
  Serial.print("Startup Offset Recorded: "); Serial.println(startingOffset);
  Serial.println("Type 'M' in the Serial Monitor and press Enter to move 90 degrees.");
  Serial.println("========================================");
}

void loop() {
  if (Serial.available()) {
    char cmd = Serial.read();
    
    // If user types 'M' or 'm'
    if (cmd == 'M' || cmd == 'm') {
      
      Serial.println("\nCommand Received: Moving Stepper 1600 steps (90 deg)...");
      
      // Read where we are BEFORE moving
      int startTicks = getZeroedTicks();
      
      // Tell motor to move 1600 steps relative to where it is right now
      stepper->move(1600); 
      
      delay(10);
      while (stepper->isRunning()) {
        // Wait for motor to finish moving
        delay(1); 
      }
      
      // Give the physical arm half a second to stop vibrating
      delay(500); 
      
      // Read the physical result AFTER moving
      int rawAfter = readEncoder();
      int endTicks = getZeroedTicks();
      
      // Calculate the delta (change), handling the 360-degree wrap-around
      int deltaTicks = endTicks - startTicks;
      if (deltaTicks < -2048) deltaTicks += 4096;
      if (deltaTicks > 2048) deltaTicks -= 4096;
      
      Serial.println("--- MOVEMENT COMPLETE ---");
      Serial.print("Raw AS5600 Reading (If 0 = Loose Wire!) : "); Serial.println(rawAfter);
      Serial.print("Expected Encoder Ticks for 90 deg       : 1024\n");
      Serial.print("Actual Ticks Moved (Delta)              : "); Serial.println(deltaTicks);
      
      // Calculate the difference between expected and actual
      int error = 1024 - deltaTicks;
      Serial.print("Error / Difference                      : "); Serial.print(error); Serial.println(" ticks");
      
      Serial.println("\nType 'M' to move ANOTHER 90 degrees forward.");
    }
  }
}
